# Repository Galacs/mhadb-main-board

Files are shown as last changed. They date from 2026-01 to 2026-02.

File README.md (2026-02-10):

# MHADB Main board

ESP32-S3 Mhadb line follower main pcb with can interfaces and integrated BMS and 5b buck converter

## IC List

- ESP32-S3-WROOM
- LDL212 (3v3 LDO)
- BQ77905 (3S battery protection)
- TPS56A37 (5v smps)
- SN65HVD (CAN transceiver)
- TMP117 (I2C temperature sensor)

## Related repositories

- [Galacs/mhadb-2208-bldc-drv](https://github.com/Galacs/mhadb-2208-bldc-drv)
- [Galacs/mhadb-line-sensor](https://github.com/Galacs/mhadb-line-sensor)
- [Galacs/mhadb-firmware](https://github.com/Galacs/mhadb-firmware)

## Top preview



## Preview 3d render



## Pictures



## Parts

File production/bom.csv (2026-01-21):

Designator | Footprint | Quantity | Value | LCSC Part #
AE1 | Johanson_2450AT18x100 | 1 | Antenna | C127629
BZ1 | MagneticBuzzer_Huaneng_MLT-5020 | 1 | Buzzer | C94598
C1, C2 | 0402 | 2 | 12p | C1547
C10, C13, C20, C23, C27, C8 | 0402 | 6 | 1u | C52923
C11, C16, C17, C22, C24, C25, C26, C28, C3, C4, C5, C6, C7, C9 | 0402 | 14 | 0u1 | C307331
C12, C15 | 0805 | 2 | 10u | C440198
C14 | 0402 | 1 | 4u7 | C23733
C18, C19 | 0402 | 2 | 1p2 | C76899
C21 | 0402 | 1 | 10u | C15525
C29 | 0402 | 1 | 47p | C1567
C30, C31 | 0805 | 2 | 22u | C45783
D1, D10, D11, D12, D2, D3, D4, D6 | Diode_DFN1006 | 8 | H5VU10U | C22395519
D13, D18 | 0805 | 2 | GREEN | C2297
D16 | 0603 | 1 | WHITE | C2290
D17 | 0805 | 1 | YELLOW | C2296
D5, D9 | D_SMA | 2 | D_Schottky | C22452
D7 | D_SOD-323 | 1 | 100 | C2128
D8 | D_SOD-123 | 1 | 16 | C19077429
J3 | USB_C_Receptacle_HRO_TYPE-C-31-M-12 | 1 | USB_C_Receptacle_USB2.0_14P | C393939
J4 | AMASS_XT30U-M_1x02_P5.0mm_Vertical | 1 | Conn_01x02 | C99101
J5, J6 | JST_PH_B3B-PH-K_1x03_P2.00mm_Vertical | 2 | Conn_01x03 | C131339
J7 | JST_PH_S4B-PH-K_1x04_P2.00mm_Horizontal | 1 | Conn_01x04 | C157926
J9 | PinHeader_1x02_P2.54mm_Vertical | 1 | Conn_01x02_Pin
L1 | 0402 | 1 | 24n | C167472
L2 | L_10.4x10.4_H4.8 | 1 | 5u6 | C41407183
L3 | 0402 | 1 | 6n8 | C77110
Q1, Q2 | Vishay_PowerPAK_1212-8_Single | 2 | Q_NMOS | C111309
Q3 | SOT-323_SC-70 | 1 | Q_NMOS | C28646265
R1, R2, R5, R7 | 0402 | 4 | 1k | C11702
R10, R16 | 0402 | 2 | 1M | C26083
R11, R20, R21, R23, R27, R28 | 0402 | 6 | 10k | C25744
R12, R14, R26, R29, R3, R30, R31, R4 | 0402 | 8 | 5k1 | C25905
R13 | 1206 | 1 | 120 | C17909
R15 | 0603 | 1 | 3M | C23156
R17 | 0603 | 1 | 470k | C23178
R18 | 0402 | 1 | 510 | C25123
R19 | 0402 | 1 | 52k3 | C26982
R22 | 0402 | 1 | 470 | C25117
R24, R25 | 0402 | 2 | 22 | C25092
R32 | 0402 | 1 | 73k2 | C26986
R50 | 0402 | 1 | 0 | C17168
R6, R9 | 0402 | 2 | 100 | C25076
R8 | 1206 | 1 | 10m/1W | C105362
SW2 | PinHeader_1x02_P2.54mm_Vertical | 1 | SW_Push
SW3, SW4 | SW_SPST_TS-1088-xR020 | 2 | SW_Push | C720477
SW5 | JST_PH_B2B-PH-K_1x02_P2.00mm_Vertical | 1 | SW_Push | C131337
U1 | TSSOP-20_4.4x6.5mm_P0.65mm | 1 | BQ77905 | C2866527
U2 | SOIC-8_3.9x4.9mm_P1.27mm | 1 | SN65HVD230 | C12084
U3 | DFN-6-1EP_2x2mm_P0.5mm_ST | 1 | LDL212PV33R | C2969892
U4 | Texas_RPA0010A_VQFN-HR-10_3x3mm_P0.5mm | 1 | TPS56A37 | C22392669
U5 | QFN-56-1EP_7x7mm_P0.4mm_EP4x4mm_ThermalVias | 1 | ESP32-S3FN8 | C3013940
U6 | WSON-6-1EP_2x2mm_P0.65mm_EP1x1.6mm | 1 | TMP117AIDRV | C699536
Y1 | Crystal_SMD_2016-4Pin_2.0x1.6mm | 1 | 48M | C7206306

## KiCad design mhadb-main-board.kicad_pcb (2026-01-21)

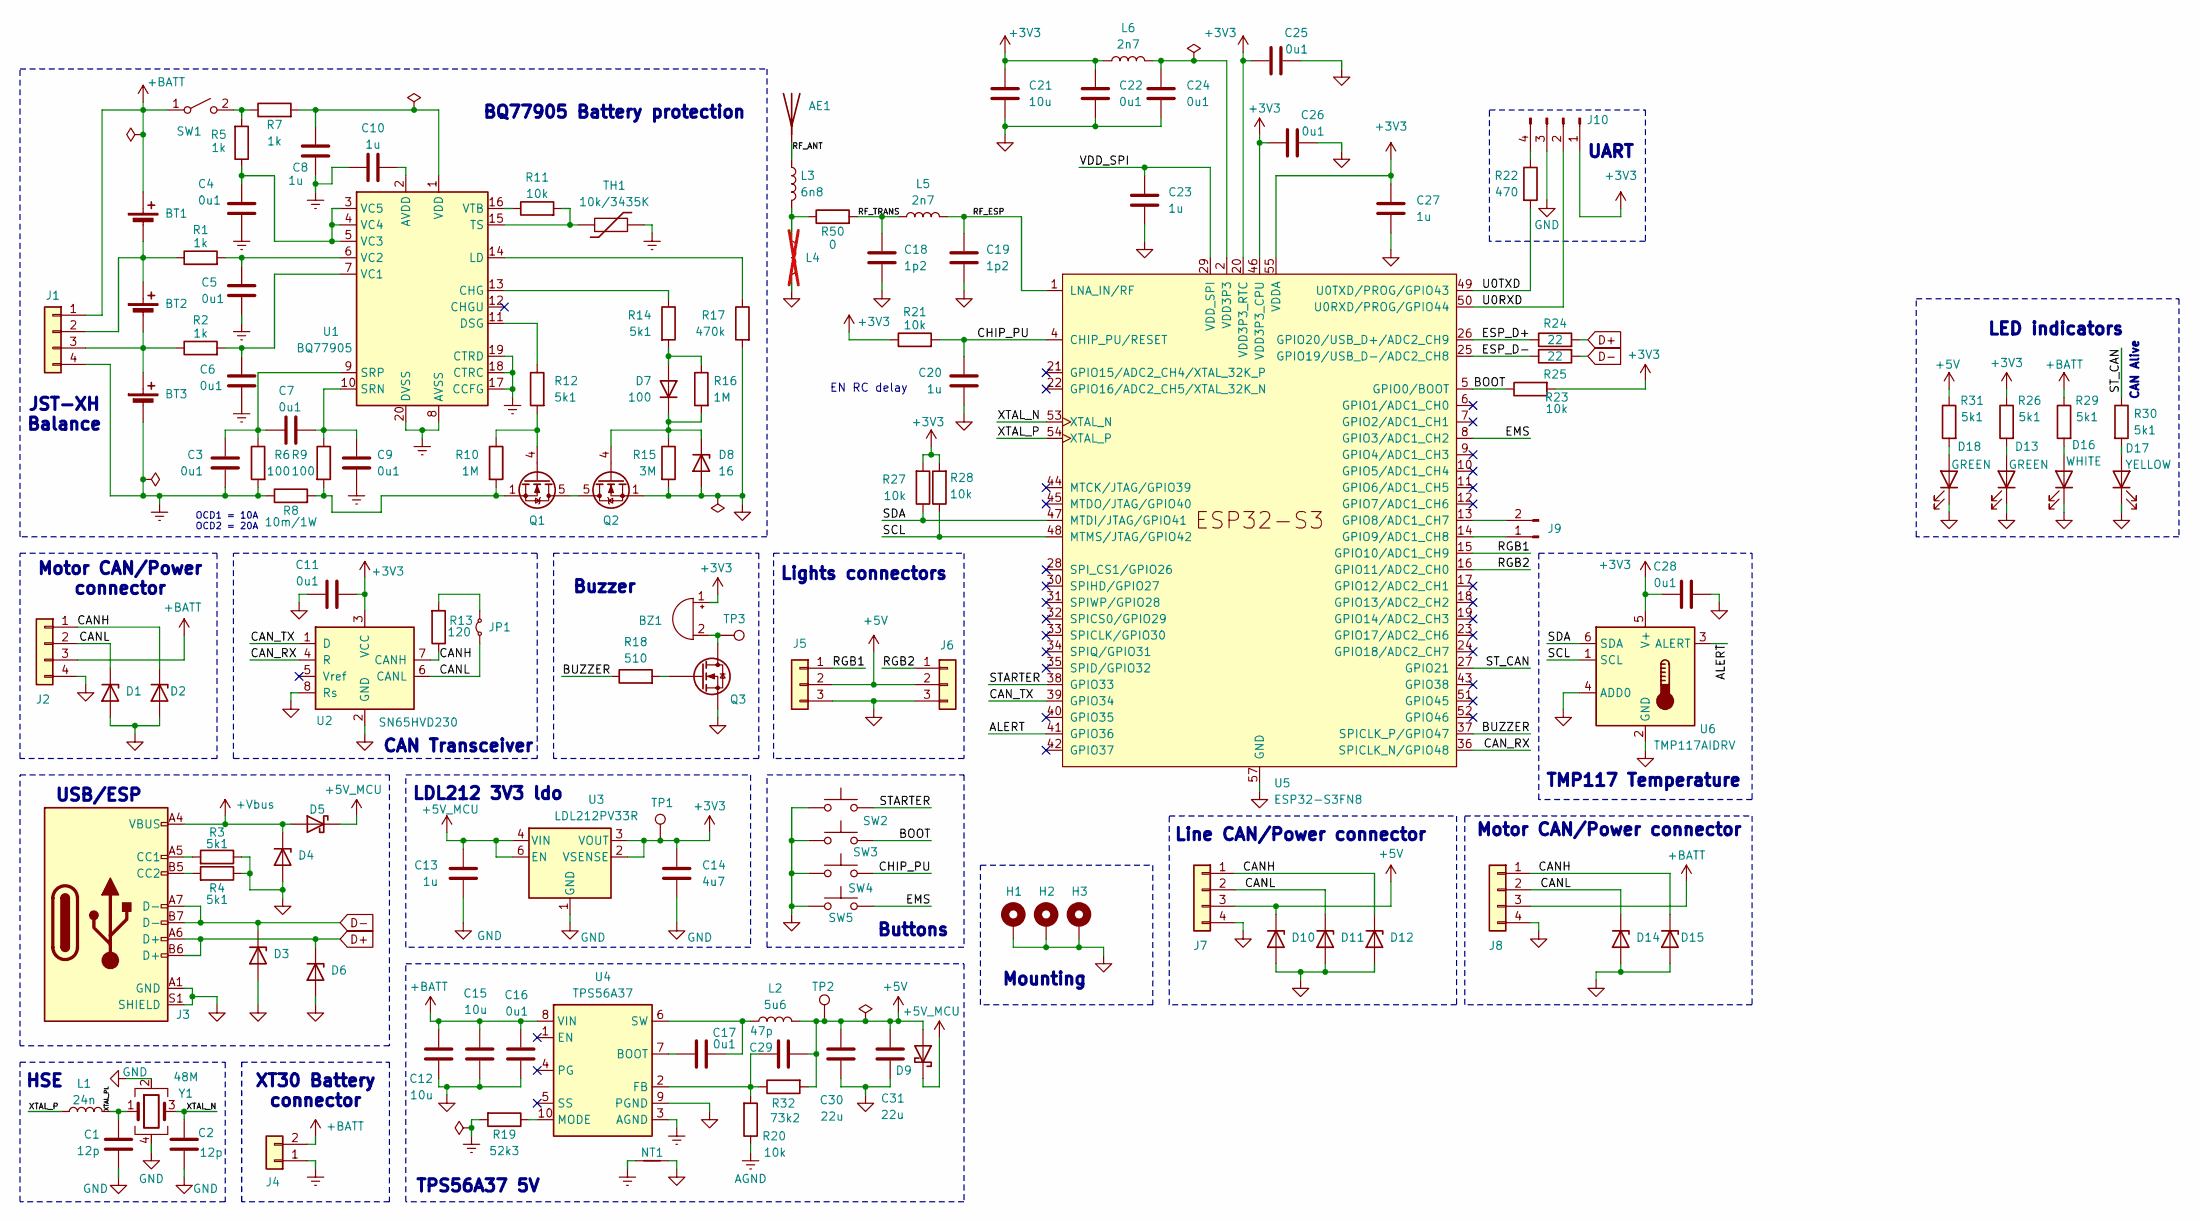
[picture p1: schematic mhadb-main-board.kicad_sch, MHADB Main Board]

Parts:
AE1: Antenna; Johanson_2450AT18x100; Manufacturer Part Number RFANT3216120A5T; JLCPCB Part # C127629
BT1, BT2, BT3: Battery_Cell; BatteryHolder_MYOUNG_BH-18650-B1BA002
BZ1: Buzzer; MagneticBuzzer_Huaneng_MLT-5020; Manufacturer Part Number MLT-5020; JLCPCB Part # C94598
C1, C2: 12p; C_0402_1005Metric; Manufacturer Part Number 0402CG120J500NT; JLCPCB Part # C1547
C3, C4, C5, C6, C7, C9, C11, C16, C17, C22, C24, C25, C26, C28: 0u1; C_0402_1005Metric; Manufacturer Part Number CL05B104KB54PNC; JLCPCB Part # C307331
C8, C10, C13, C20, C23, C27: 1u; C_0402_1005Metric; Manufacturer Part Number CL05A105KA5NQNC; JLCPCB Part # C52923
C12, C15: 10u; C_0805_2012Metric; Manufacturer Part Number GRM21BR61H106KE43L; JLCPCB Part # C440198
C14: 4u7; C_0402_1005Metric; Manufacturer Part Number CL05A475MP5NRNC; JLCPCB Part # C23733
C18, C19: 1p2; C_0402_1005Metric; Manufacturer Part Number GJM1555C1H1R2WB01D; JLCPCB Part # C76899
C21: 10u; C_0402_1005Metric; Manufacturer Part Number CL05A106MQ5NUNC; JLCPCB Part # C15525
C29: 47p; C_0402_1005Metric; Manufacturer Part Number 0402CG470J500NT; JLCPCB Part # C1567
C30, C31: 22u; C_0805_2012Metric; Manufacturer Part Number CL21A226MAQNNNE; JLCPCB Part # C45783
D1, D2, D3, D4, D6, D10, D11, D12, D14, D15: H5VU10U; Diode_DFN1006; Manufacturer Part Number H5VU10U; JLCPCB Part # C22395519
D5, D9: D_Schottky; D_SMA; Manufacturer Part Number SS54; JLCPCB Part # C22452
D7: 100; D_SOD-323; Manufacturer Part Number 1N4148WS; JLCPCB Part # C2128
D8: 16; D_SOD-123; Manufacturer Part Number MMSZ5246B; JLCPCB Part # C19077429
D13, D18: GREEN; LED_0805_2012Metric; Manufacturer Part Number KT-0805G; JLCPCB Part # C2297
D16: WHITE; LED_0603_1608Metric; Manufacturer Part Number KT-0603W; JLCPCB Part # C2290
D17: YELLOW; LED_0805_2012Metric; Manufacturer Part Number KT-0805Y; JLCPCB Part # C2296
H1, H2, H3: MountingHole_Pad; MountingHole_3.2mm_M3_DIN965_Pad_Thin
J1, J2, J8: Conn_01x04; JST_XH_B4B-XH-A_1x04_P2.50mm_Vertical; Manufacturer Part Number B4B-XH-A(LF)(SN); JLCPCB Part # C144395
J3: USB_C_Receptacle_USB2.0_14P; USB_C_Receptacle_HRO_TYPE-C-31-M-12; Manufacturer Part Number TYPE-C16PIN; JLCPCB Part # C393939
J4: Conn_01x02; AMASS_XT30U-M_1x02_P5.0mm_Vertical; Manufacturer Part Number XT30U-M; JLCPCB Part # C99101
J5, J6: Conn_01x03; JST_PH_B3B-PH-K_1x03_P2.00mm_Vertical; Manufacturer Part Number B3B-PH-K-S(LF)(SN); JLCPCB Part # C131339
J7: Conn_01x04; JST_PH_S4B-PH-K_1x04_P2.00mm_Horizontal; Manufacturer Part Number S4B-PH-K-S(LF)(SN); JLCPCB Part # C157926
J9: Conn_01x02_Pin; PinHeader_1x02_P2.54mm_Vertical
J10: Conn_01x04_Pin; PinHeader_1x04_P2.54mm_Vertical
JP1: Jumper_2_Small_Bridged; SolderJumper-2_P1.3mm_Open_RoundedPad1.0x1.5mm
L1: 24n; L_0402_1005Metric; Manufacturer Part Number LQW15AN24NG00D; JLCPCB Part # C167472
L2: 5u6; L_10.4x10.4_H4.8; Manufacturer Part Number DH1040H-5R6M; JLCPCB Part # C41407183
L3: 6n8; L_0402_1005Metric; Manufacturer Part Number LQG15HS6N8J02D; JLCPCB Part # C77110
L4: L; L_0402_1005Metric; not fitted
L5, L6: 2n7; L_0402_1005Metric; Manufacturer Part Number LQG15HS2N7S02D; JLCPCB Part # C77108
NT1: NetTie_2; NetTie-2_SMD_Pad0.5mm
Q1, Q2: Q_NMOS; Vishay_PowerPAK_1212-8_Single; Manufacturer Part Number SIS412DN-T1-GE3; JLCPCB Part # C111309
Q3: Q_NMOS; SOT-323_SC-70; Manufacturer Part Number BSS138W; JLCPCB Part # C28646265
R1, R2, R5, R7: 1k; R_0402_1005Metric; Manufacturer Part Number 0402WGF1001TCE; JLCPCB Part # C11702
R3, R4, R12, R14, R26, R29, R30, R31: 5k1; R_0402_1005Metric; Manufacturer Part Number 0402WGF5101TCE; JLCPCB Part # C25905
R6, R9: 100; R_0402_1005Metric; Manufacturer Part Number 0402WGF1000TCE; JLCPCB Part # C25076
R8: 10m/1W; R_1206_3216Metric; Manufacturer Part Number FMF06FTHR010-LH; JLCPCB Part # C105362
R10, R16: 1M; R_0402_1005Metric; Manufacturer Part Number 0402WGF1004TCE; JLCPCB Part # C26083
R11, R20, R21, R23, R27, R28: 10k; R_0402_1005Metric; Manufacturer Part Number 0402WGF1002TCE; JLCPCB Part # C25744
R13: 120; R_1206_3216Metric; Manufacturer Part Number 1206W4F1200T5E; JLCPCB Part # C17909
R15: 3M; R_0603_1608Metric; Manufacturer Part Number 0603WAF3004T5E; JLCPCB Part # C23156
R17: 470k; R_0603_1608Metric; Manufacturer Part Number 0603WAF4703T5E; JLCPCB Part # C23178
R18: 510; R_0402_1005Metric; Manufacturer Part Number 0402WGF5100TCE; JLCPCB Part # C25123
R19: 52k3; R_0402_1005Metric; Manufacturer Part Number 0402WGF5232TCE; JLCPCB Part # C26982
R22: 470; R_0402_1005Metric; Manufacturer Part Number 0402WGF4700TCE; JLCPCB Part # C25117
R24, R25: 22; R_0402_1005Metric; Manufacturer Part Number 0402WGF220JTCE; JLCPCB Part # C25092
R32: 73k2; R_0402_1005Metric; Manufacturer Part Number 0402WGF7322TCE; JLCPCB Part # C26986
R50: 0; R_0402_1005Metric; Manufacturer Part Number 0402WGF0000TCE; JLCPCB Part # C17168
SW1: SW_SPST; PinHeader_1x02_P2.54mm_Vertical
SW2: SW_Push; PinHeader_1x02_P2.54mm_Vertical
SW3, SW4: SW_Push; SW_SPST_TS-1088-xR020; Manufacturer Part Number TS-1088-AR02016; JLCPCB Part # C720477
SW5: SW_Push; JST_PH_B2B-PH-K_1x02_P2.00mm_Vertical; Manufacturer Part Number B2B-PH-K-S(LF)(SN); JLCPCB Part # C131337
TH1: 10k/3435K; JST_PH_B2B-PH-K_1x02_P2.00mm_Vertical; Manufacturer Part Number B2B-PH-K-S(LF)(SN); JLCPCB Part # C131337
TP1, TP2, TP3: TestPoint; TestPoint_Pad_D2.0mm
U1: BQ77905; TSSOP-20_4.4x6.5mm_P0.65mm; Manufacturer Part Number BQ7790509PWR; JLCPCB Part # C2866527
U2: SN65HVD230; SOIC-8_3.9x4.9mm_P1.27mm; Manufacturer Part Number SN65HVD230DR; JLCPCB Part # C12084
U3: LDL212PV33R; DFN-6-1EP_2x2mm_P0.5mm_ST; Manufacturer Part Number LDL212PV33R; JLCPCB Part # C2969892
U4: TPS56A37; Texas_RPA0010A_VQFN-HR-10_3x3mm_P0.5mm; Manufacturer Part Number TPS56A37RPAR; JLCPCB Part # C22392669
U5: ESP32-S3FN8; QFN-56-1EP_7x7mm_P0.4mm_EP4x4mm_ThermalVias; Manufacturer Part Number ESP32-S3FH4R2; JLCPCB Part # C3013940
U6: TMP117AIDRV; WSON-6-1EP_2x2mm_P0.65mm_EP1x1.6mm; Manufacturer Part Number TMP117AIDRVR; JLCPCB Part # C699536
Y1: 48M; Crystal_SMD_2016-4Pin_2.0x1.6mm; Manufacturer Part Number R940000096; JLCPCB Part # C7206306

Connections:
+3V3: BZ1.1 (+), C11.1, C14.1, C21.1, C22.1, C25.1, C26.1, C27.1, C28.1, J10.1, L6.1, R21.1, R23.2, R26.1, R27.2, R28.2, TP1.1, U2.3 (VCC), U3.2 (VSENSE), U3.3 (VOUT), U5.20 (VDD3P3_RTC), U5.46 (VDD3P3_CPU), U5.55 (VDDA), U5.56 (VDDA), U6.5 (V+)
+5V: C29.2, C30.1, C31.1, D9.2 (A), D10.1 (K), J5.2, J6.2, J7.3, L2.2, R31.1, R32.2, TP2.1
+5V_MCU: C13.1, D5.1 (K), D9.1 (K), U3.4 (VIN), U3.6 (EN)
+BATT: BT1.1 (+), C12.1, C15.1, C16.1, J1.1, J2.3, J4.2, J8.3, R29.1, SW1.1 (A), U4.8 (VIN)
+Vbus: D4.1 (K), D5.2 (A), J3.A4 (VBUS), J3.A9 (VBUS), J3.B4 (VBUS), J3.B9 (VBUS)
/ALERT: U5.41 (GPIO36), U6.3 (ALERT)
/BOOT: R23.1, SW3.2, U5.5 (GPIO0/BOOT)
/BUZZER: R18.1, U5.37 (SPICLK_P/GPIO47)
/CANH: D2.1 (K), D12.1 (K), D15.1 (K), J2.1, J7.1, J8.1, R13.1, U2.7 (CANH)
/CANL: D1.1 (K), D11.1 (K), D14.1 (K), J2.2, J7.2, J8.2, JP1.1 (A), U2.6 (CANL)
/CAN_RX: U2.4 (R), U5.36 (SPICLK_N/GPIO48)
/CAN_TX: U2.1 (D), U5.39 (GPIO34)
/CHIP_PU: C20.1, R21.2, SW4.2, U5.4 (CHIP_PU/RESET)
/EMS: SW5.2, U5.8 (GPIO3/ADC1_CH2)
/ESP_D+: R24.1, U5.26 (GPIO20/USB_D+/ADC2_CH9)
/ESP_D-: R25.1, U5.25 (GPIO19/USB_D-/ADC2_CH8)
/RF_ANT: AE1.1 (A), L3.1
/RF_ESP: C19.1, L5.2, U5.1 (LNA_IN/RF)
/RF_TRANS: C18.1, L5.1, R50.2
/RGB1: J5.1, U5.15 (GPIO10/ADC1_CH9)
/RGB2: J6.1, U5.16 (GPIO11/ADC2_CH0)
/SCL: R28.1, U5.48 (MTMS/JTAG/GPIO42), U6.1 (SCL)
/SDA: R27.1, U5.47 (MTDI/JTAG/GPIO41), U6.6 (SDA)
/STARTER: SW2.2, U5.38 (GPIO33)
/ST_CAN: R30.1, U5.27 (GPIO21)
/U0RXD: J10.2, U5.50 (U0RXD/PROG/GPIO44)
/U0TXD: R22.2, U5.49 (U0TXD/PROG/GPIO43)
/VDD_SPI: C23.1, U5.29 (VDD_SPI)
/XTAL_N: C2.1, U5.53 (XTAL_N), Y1.3
/XTAL_P: L1.1, U5.54 (XTAL_P)
/XTAL_PL: C1.2, L1.2, Y1.1
AGND: NT1.1, R19.2, R20.1, U4.3 (AGND)
BGND: BT3.2 (-), C3.2, C4.2, C5.2, C6.2, C8.1, C9.2, C10.2, J1.4, J4.1, R6.2, R8.1, TH1.2, U1.8 (AVSS), U1.17 (CCFG), U1.18 (CTRC), U1.19 (CTRD), U1.20 (DVSS)
D+: D6.1 (K), J3.A6 (D+), J3.B6 (D+), R24.2
D-: D3.1 (K), J3.A7 (D-), J3.B7 (D-), R25.2
GND: C1.1, C2.2, C11.2, C12.2, C13.2, C14.2, C15.2, C16.2, C18.2, C19.2, C20.2, C21.2, C22.2, C23.2, C24.2, C25.2, C26.2, C27.2, C28.2, C30.2, C31.2, D1.2 (A), D2.2 (A), D3.2 (A), D4.2 (A), D6.2 (A), D8.2 (A), D10.2 (A), D11.2 (A), D12.2 (A), D13.1 (K), D14.2 (A), D15.2 (A), D16.1 (K), D17.1 (K), D18.1 (K), H1.1, H2.1, H3.1, J2.4, J3.A1 (GND), J3.A12 (GND), J3.B1 (GND), J3.B12 (GND), J3.S1 (SHIELD), J5.3, J6.3, J7.4, J8.4, J10.3, L4.2, NT1.2, Q2.1 (S), Q2.2 (S), Q2.3 (S), Q3.2 (S), R3.1, R4.1, R15.2, R17.2, SW2.1, SW3.1, SW4.1, SW5.1, U2.2 (GND), U2.8 (Rs), U3.1 (GND), U4.9 (PGND), U5.57 (GND), U6.2 (GND), U6.4 (ADD0), U6.7, Y1.2, Y1.4
unnamed: BZ1.2 (-), Q3.3 (D), TP3.1
unnamed: D7.2 (A), R14.2, R16.1
unnamed: D7.1 (K), D8.1 (K), Q2.4 (G), R15.1, R16.2
unnamed: D13.2 (A), R26.2
unnamed: D16.2 (A), R29.2
unnamed: D17.2 (A), R30.2
unnamed: D18.2 (A), R31.2
unnamed: BT1.2 (-), BT2.1 (+), J1.2, R1.1
unnamed: BT2.2 (-), BT3.1 (+), J1.3, R2.1
unnamed: J3.A5 (CC1), R3.2
unnamed: J3.B5 (CC2), R4.2
unnamed: J9.1, U5.14 (GPIO9/ADC1_CH8)
unnamed: J9.2, U5.13 (GPIO8/ADC1_CH7)
unnamed: J10.4, R22.1
unnamed: JP1.2 (B), R13.2
unnamed: L3.2, L4.1, R50.1
unnamed: Q1.5 (D), Q2.5 (D)
unnamed: Q1.4 (G), R10.1, R12.2
unnamed: Q1.1 (S), Q1.2 (S), Q1.3 (S), R8.2, R9.2, R10.2
unnamed: Q3.1 (G), R18.2
unnamed: R5.2, R7.1, SW1.2 (B)
unnamed: C10.1, U1.2 (AVDD)
unnamed: R14.1, U1.13 (CHG)
unnamed: R12.1, U1.11 (DSG)
unnamed: R17.1, U1.14 (LD)
unnamed: C7.1, C9.1, R9.1, U1.10 (SRN)
unnamed: C3.1, C7.2, R6.1, U1.9 (SRP)
unnamed: R11.2, TH1.1, U1.15 (TS)
unnamed: C6.1, R2.2, U1.7 (VC1)
unnamed: C5.1, R1.2, U1.6 (VC2)
unnamed: C4.1, R5.1, U1.3 (VC5), U1.4 (VC4), U1.5 (VC3)
unnamed: C8.2, R7.2, U1.1 (VDD)
unnamed: R11.1, U1.16 (VTB)
unnamed: C17.1, U4.7 (BOOT)
unnamed: C29.1, R20.2, R32.1, U4.2 (FB)
unnamed: R19.1, U4.10 (MODE)
unnamed: C17.2, L2.1, U4.6 (SW)
VDD3P3: C24.1, L6.2, U5.2 (VDD3P3), U5.3 (VDD3P3)

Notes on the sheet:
Motor CAN/Power connector
Buttons
XT30 Battery connector
TMP117 Temperature
Buzzer
USB/ESP
CAN Transceiver
HSE
JST-XH Balance
Lights connectors
LDL212 3V3 ldo
UART
BQ77905 Battery protection
TPS56A37 5V
OCD1 = 10A OCD2 = 20A
Mounting
Motor CAN/Power connector
Line CAN/Power connector
CAN Alive
EN RC delay
LED indicators

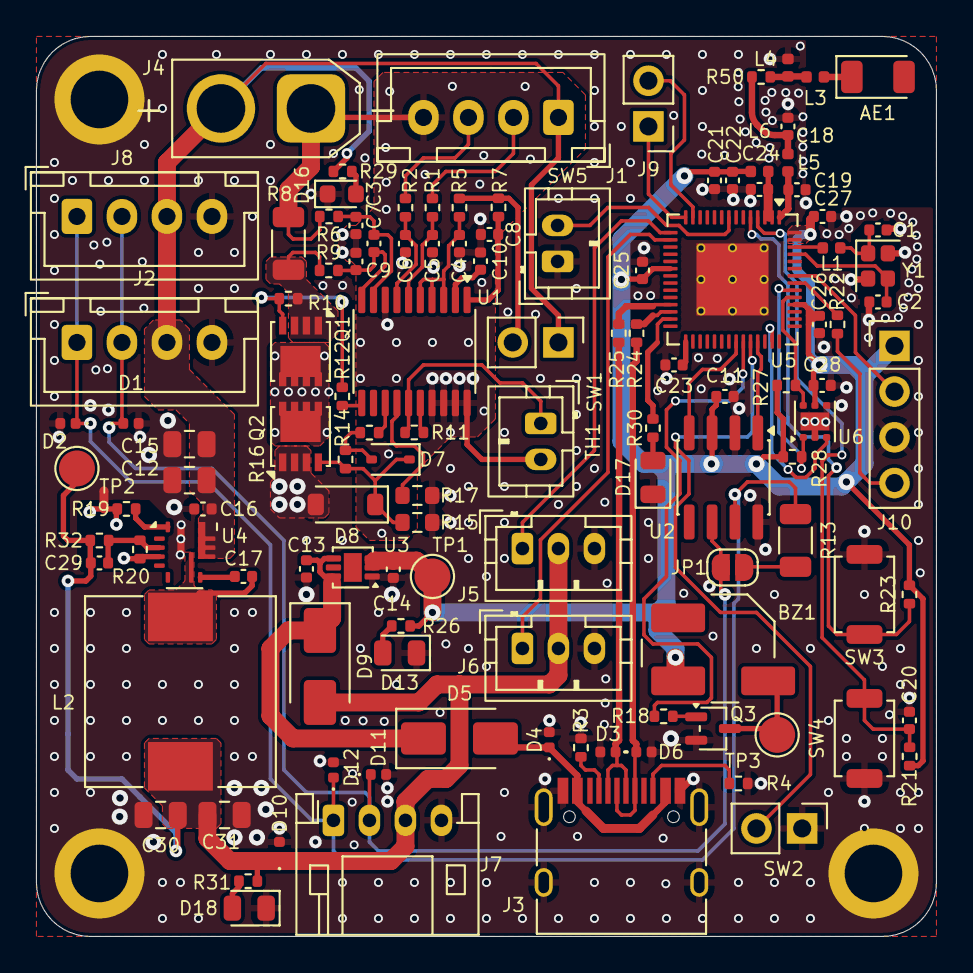
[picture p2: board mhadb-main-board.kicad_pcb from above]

Board: 4 copper layers, 50.0 x 50.0 mm, 122 parts (0 on the bottom side), 74 nets.

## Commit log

2026-01-10 schem: import ESP32-S3FN8
    [mhadb-main-board.kicad_pcb, mhadb-main-board.kicad_sch]
2026-01-10 schem: import 2.4GHZ rf circuit
    [mhadb-main-board.kicad_sch]
2026-01-10 schem: import reset circuit
    [mhadb-main-board.kicad_sch]
2026-01-10 schem: import HSE oscilator
    [mhadb-main-board.kicad_sch]
2026-01-10 schem: add BOOT pullup
    [mhadb-main-board.kicad_sch]
2026-01-10 schem: import BOOT and CHIP_PU btns
    [mhadb-main-board.kicad_sch]
2026-01-10 schem: add USB-C connector
    [mhadb-main-board.kicad_sch]
2026-01-10 schem: import UART connector
    [mhadb-main-board.kicad_sch]
2026-01-10 schem: import LDL212 3V3 LDO
    [mhadb-main-board.kicad_sch]
2026-01-10 schem: add 2 motor can/power connector
    [mhadb-main-board.kicad_sch]
2026-01-10 schem: add line can/power connector
    [mhadb-main-board.kicad_sch]
2026-01-10 schem: import TPS5430 5v from motor-power-poc
    [mhadb-main-board.kicad_sch]
2026-01-10 schem: add SN65HVD230 CAN Transceiver
    [mhadb-main-board.kicad_sch]
2026-01-10 schem: add XT30 battery connector
    [mhadb-main-board.kicad_sch]
2026-01-10 schem: import BQ77905 Battery protection
    [mhadb-main-board.kicad_sch]
2026-01-10 schem: add passive buzzer
    [mhadb-main-board.kicad_sch]
2026-01-10 schem: add EMS button
    [mhadb-main-board.kicad_sch]
2026-01-10 schem: add starter connector
    [mhadb-main-board.kicad_sch]
2026-01-11 schem: switch thermistor to 2 pin ph connector
    [mhadb-main-board.kicad_sch]
2026-01-11 schem: add spare GPIIOs
    [mhadb-main-board.kicad_sch]
2026-01-11 schem: add 2 JST PH 3 pin RGB led connectors
    [mhadb-main-board.kicad_sch]
2026-01-11 schem: add no connects
    [mhadb-main-board.kicad_sch]
2026-01-11 schem: add test points
    [mhadb-main-board.kicad_sch]
2026-01-11 schem: switch pins for strapping
    [mhadb-main-board.kicad_sch]
2026-01-11 schem: run and fix ERC
    [mhadb-main-board.kicad_sch]
2026-01-11 schem: add ESP32 to BOM
    [mhadb-main-board.kicad_sch]
2026-01-11 schem: add title
    [mhadb-main-board.kicad_sch]
2026-01-11 schem: renumber
    [mhadb-main-board.kicad_sch]
2026-01-11 pcb: import stackup and constraints
    [mhadb-main-board.kicad_pcb]
2026-01-11 pcb: import components from schem
    [mhadb-main-board.kicad_pcb]
2026-01-11 pcb: add missing 3d models
    [mhadb-main-board.kicad_pcb]
2026-01-11 schem/pcb: fix XT30 polarity
    [mhadb-main-board.kicad_pcb, mhadb-main-board.kicad_sch]
2026-01-11 schem/pcb: changed esp32 footprint
    [mhadb-main-board.kicad_pcb, mhadb-main-board.kicad_sch]
2026-01-11 pcb: add board outline
    [mhadb-main-board.kicad_pcb]
2026-01-11 schem/pcb: add mounting holes
    [mhadb-main-board.kicad_pcb, mhadb-main-board.kicad_sch]
2026-01-11 pcb: refine layout of every block
    [mhadb-main-board.kicad_pcb]
2026-01-11 schem: remove extra testpoints
    [mhadb-main-board.kicad_sch]
2026-01-11 pcb: initial layout
    [mhadb-main-board.kicad_pcb, mhadb-main-board.kicad_sch]
2026-01-11 schem/pcb: add TMP117 temp sensor
    [mhadb-main-board.kicad_pcb, mhadb-main-board.kicad_sch]
2026-01-11 pcb: changed outline to 50x50mm
    [mhadb-main-board.kicad_pcb, mhadb-main-board.kicad_sch]
2026-01-11 pcb: switched to 4 layer stackup
    [mhadb-main-board.kicad_pcb]
2026-01-11 pcb: add gnd planes
    [mhadb-main-board.kicad_pcb]
2026-01-11 pcb: add gnd vias
    [mhadb-main-board.kicad_pcb]
2026-01-11 pcb: add BMS BGND plane
    [mhadb-main-board.kicad_pcb]
2026-01-11 pcb: add BGND vias
    [mhadb-main-board.kicad_pcb]
2026-01-11 pcb: add grid/drill origin
    [mhadb-main-board.kicad_pcb]
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2026-01-11 pcb: add RF routing
    [mhadb-main-board.kicad_pcb, mhadb-main-board.kicad_sch]
2026-01-11 pcb: add HSE crystal routing
    [mhadb-main-board.kicad_pcb]
2026-01-11 pcb: add USB routing
    [mhadb-main-board.kicad_pcb]
2026-01-11 pcb: add CAN routing
    [mhadb-main-board.kicad_pcb]
2026-01-11 pcb: add UART routing
    [mhadb-main-board.kicad_pcb]
2026-01-11 pcb: add SMPS routing
    [mhadb-main-board.kicad_pcb]
2026-01-11 pcb: add BQ77905 Battery protection routing
    [mhadb-main-board.kicad_pcb]
2026-01-11 pcb: add I2C routing
    [mhadb-main-board.kicad_pcb]
2026-01-11 pcb: add 5v pwr routing
    [mhadb-main-board.kicad_pcb]
2026-01-11 pcb: add 3V3 pwr routing
    [mhadb-main-board.kicad_pcb]
2026-01-11 pcb: add RGB connectors routing
    [mhadb-main-board.kicad_pcb]
2026-01-11 pcb: add spare GPIOs routing
    [mhadb-main-board.kicad_pcb]
2026-01-11 pcb: add buzzer routing
    [mhadb-main-board.kicad_pcb]
2026-01-11 pcb: add BOOT and CHIP_PU routing
    [mhadb-main-board.kicad_pcb]
2026-01-11 pcb: add EMS button routing
    [mhadb-main-board.kicad_pcb]
2026-01-11 pcb: add starter routing
    [mhadb-main-board.kicad_pcb]
2026-01-11 pcb: add missing connections
    [mhadb-main-board.kicad_pcb, mhadb-main-board.kicad_sch]
2026-01-11 pcb: add stitching vias
    [mhadb-main-board.kicad_pcb]
2026-01-11 pcb: run and fix DRC
    [mhadb-main-board.kicad_pcb]
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2026-01-11 pcb: remove unused internal pads
    [mhadb-main-board.kicad_pcb]
2026-01-11 pcb(silkscreen): clean reference designators
    [mhadb-main-board.kicad_pcb]
2026-01-11 schem/pcb: add status LEDs
    [mhadb-main-board.kicad_pcb, mhadb-main-board.kicad_sch]
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2026-01-11 pcb(silkscreen): replace placeholder
    [mhadb-main-board.kicad_pcb]
2026-01-11 schem: updated SMPS L BOM
    [mhadb-main-board.kicad_pcb, mhadb-main-board.kicad_sch]
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2026-01-21 schem/pcb: remove TPS5430 5v SMPS
    [mhadb-main-board.kicad_pcb, mhadb-main-board.kicad_sch]
2026-01-21 schem/pcb: add TPS56A37 5V smps
    [mhadb-main-board.kicad_pcb, mhadb-main-board.kicad_sch]
